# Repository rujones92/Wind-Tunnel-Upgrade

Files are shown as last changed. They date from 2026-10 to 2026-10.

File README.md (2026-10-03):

# Wind Tunnel Upgrade: motorized 6-component sting balance

## ▶ View the website: [rujones92.github.io/Wind-Tunnel-Upgrade](https://rujones92.github.io/Wind-Tunnel-Upgrade/)

This repository hosts the design package for a motorized sting force balance for a university low-speed wind
tunnel (test section 26.25 × 11.25 × 30 in, 70-100 mph). The tunnel tests 3D-printed aircraft models. A one-piece
aluminium strain-gauge balance measures all six force and moment components. Stepper motors roll (±90°), pitch
(-6° to +20°) and yaw (±15°) the model, controlled from a Raspberry Pi station.

Open the link above to browse the package. GitHub's file view shows `index.html` as source code, so use the
website link instead. The website includes:

- **Overview, Requirements, Balance, Models & pod, Motion, Electronics & control, Calibration:** the design and how
  it works, with CAD renders and wiring diagrams
- **Drawings:** 35 GD&T sheets (assemblies with parts lists and every machined part), as PDF
- **Machining cost:** a real JLCCNC quote, the expected final order and an ordering checklist
- **Implementation plan, Design history, References:** phases, budget, risks, literature, and downloads of all STEP
  files and scripts

The drawings are REV A and AI-assisted. They have not yet been checked or approved for manufacture. Yaw-carriage
sheets (5xx) are preliminary until the tunnel's downstream bay is measured.

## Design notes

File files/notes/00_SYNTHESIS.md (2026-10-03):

# Reference review — synthesis (2026-10-02)

Combined from 7 reader agents (276 pages, read as page images + text layer). Per-document notes are in this folder.
Reviewed against `balance_sizing.py` (7075-T651, 3-component, two-moment necks + 2-plate Z axial flexure).

## What the references confirm
- Monolithic balance; fwd moment section → axial section → aft moment section (LaRC Figs 4, 5, 8).
- 7075 is on LaRC's material list; 350 Ω gauges, 5 V excitation, 4-active-arm bridges, CEA-13 on aluminum.
- Necks 0.50 × 0.25 in → 1.03 mV/V, inside LaRC's 1–1.5 mV/V target; combined-load SF 10.7.
- Independent check: Bharath 8 mm square neck has the same section modulus (0.0052 in³) → same ~520 µε.
- Two-moment method with BMC midway between gauges is exactly the Gulfstream balance in the NASA 2010 calibration paper.

## Design changes indicated
| # | Issue | Source | Change |
|---|---|---|---|
| 1 | Axial output 0.78 mV/V < 1.0 target | LaRC p.8–9 | Raise strain. Note: plate t=0.020" gives 1.21 mV/V but is fragile and hard to gauge |
| 2 | Axial gauges sit on load-carrying plates (~107 µε of N/m strain vs 388 µε signal) | LaRC Fig 8 | Preferred: two ungauged outer flex plates + one centreline gauged measuring beam |
| 3 | Gauge centre 0.06" from root too close for gauge backing/tabs and fillets | Gage proc. p.7; LaRC p.9 | Root fillets r≈0.03–0.06"; gauge centres ≥0.08–0.10" from fillet; recompute |
| 4 | Clamping 60 psi on a 0.025" plate in a 0.75" window | Gage proc. p.7, p.30 | Clamp both inner gauges in one stack with backing blocks outside both plates; 0.75" window is minimum |
| 5 | Hot-cure adhesive (M-610/M-450 at 340–350°F, hours) over-ages 7075-T651 (aged ~250°F) | Gage proc. p.7, p.70 | Use reduced cure (M-610 250°F/3 h + 275°F post, p.32) or AE-10 room-temp; or switch to 17-4PH H1025 |
| 6 | Resolution assumption 0.05% FS too optimistic | LaRC Figs 14–15 | Budget 0.2–0.5% FS (LaRC itself: 0.06–0.17%, 2σ) |
| 7 | Cruise drag is only 5–15% of 2 lbf axial FS | LaRC p.3–4 | Consider ~1 lbf axial FS with hard stops, or a second low-range balance for polars |
| 8 | No temperature sensing | LaRC Fig 12; Gage proc. p.8–9 | RTD/thermistor on balance; matched-lot gauges; software temperature correction |
| 9 | Sting/pod ratio 1/2 = at limit | TN D-4021 p.5 + Love ref. | 7/8" sting or 2.25" pod (ratio ≈0.44); ≥10–12" straight sting before flare (≥5 base dia) |
| 10 | Base/cavity pressure not handled | TN D-4021 p.8 | 2–4 base taps + 1 cavity tap; subtract (p_base − p∞)·A_base from axial |
| 11 | Joints undefined | LaRC p.6–7 | Model end: bore fit + interference dowel; sting end: flange (preferred) or 1 in/ft taper + key + double nut |
| 12 | Wiring across flexures | Gage proc. p.7–8; part 2 p.57–64 | Terminals on shoulders/rails, not necks; groove for wires crossing axial flexure; strain-relief loops |

## Calibration plan (NASA 2010, Ulbrich & Bader)
- Responses: neck-output difference (∝ N) and sum (∝ m), plus axial. Regress against BMC loads.
- Term selection: start intercept + main term, add terms only if p < 0.001, VIF < 5, PRESS improves. Full quadratic overfits (VIF ~23,000).
- Schedule: ~90 fit points + 10–15 withheld check points; N at BMC and ±1, ±2 in (both sides of BMC to decorrelate N and m); pure couples; A alone and combined with N, m; load up and down; flip balance for negative loads.
- Re-level with an inclinometer after each load (0.18° deflection tilts N into A by 1.5–3% of A FS).
- Expected sensitivities: ~36.9 µV/V per in-lbf per neck; difference ≈ 88.6 µV/V per lbf; sum ≈ 73.9 µV/V per in-lbf.
- Acceptance: residual SD ≤ 0.1–0.25% FS, max residual ≤ 3σ, PRESS ≈ fit residual, check-point errors in load units.

## Gauge installation & checks (NASA TM-110327)
Degrease → abrade (hobby: acid conditioner/neutralizer) → bond (±0.005" placement) → cure → wire with equal-length leads → checks:
leakage > 10,000 MΩ at ≤15 V (megohmmeter), zero within ±0.4 mV/V (Manganin trim or amplifier offset), tap test, hand-load test,
warm-box zero drift test, thin moisture coat (≤0.005", identical on both plates; RTV over terminals only).
Avoid M-Bond 200 (cyanoacrylate) for a long-life balance.

## Alternative (2014 external 6-comp paper)
External platform balances reach ~0.3% FS but strut drag lands in the drag reading; roughly 3–5× the work for 6-comp.
Keep internal sting balance as primary; 3-component floor platform as fallback.

## Papers worth obtaining next (cited by the references)
- Love, NACA RM L53K12 (sting diameter and length effects) — free on NTRS
- Webb/Ladson 2001 monolithic balance thesis; Pieterse 2008; Lee et al. 2005
- "A Three-Component Strain-Gauged Sting Balance for Small Low-Speed Wind Tunnels", Aeronautical Journal (paywalled)

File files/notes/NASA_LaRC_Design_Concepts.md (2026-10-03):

# NASA LaRC Strain Gage Balance Design Concepts (Rhew, 1999) - reading notes

Source: `references/NASA_LaRC_Strain_Gage_Balance_Design_Concepts_1999.pdf` (18 PDF pages; journal pages 525-541, PDF p.18 is blank).
Page references below are given as **PDF page (journal page)**, e.g. p.10 (534).

## 1. Summary

An overview of how NASA Langley designs, builds, gauges and calibrates internal sting-mounted six-component balances. It is a process and philosophy paper, not a design handbook. It gives only a few hard numbers (output target, materials and hardness, EDM tolerances, bridge zero-balance limit, gauge and adhesive part numbers, calibration matrix size and achieved accuracy). It has **no sizing formulas** apart from the strain-output relation. Its core messages:

1. Make the balance from **one piece of material** (no joints). Joints cause hysteresis and zero shift.
2. **Match the balance's full-scale loads to the test's expected loads** to get the best resolution.
3. Size each measuring section for **1-1.5 mV/V at full scale**, while keeping strain safe under **all six loads applied together**.
4. Make each bridge sensitive to its own component and insensitive to the others. Do this through the section geometry, gauge placement and bridge wiring.
5. Do the work carefully: EDM finishing passes, tolerances of 0.0002-0.0005 in, an experienced gauger, temperature compensation, and a full second-order calibration.

## 2. Design rules and numeric criteria

### Inputs needed before design (p.4 / 528)
Expected loads in all 6 DOF; where the balance sits in the model; maximum diameter and length; environment (temperature, pressure, moisture, dynamics, airflow, corrosion); model-end (metric) and sting-end (non-metric) interfaces; required accuracy and resolution; electrical interfaces; DAQ specs; data-reduction software; set-up and checkout equipment. Start from a similar past design. Iterate with strength-of-materials code; FEA is "beginning to be evaluated" for stress concentrations, thermal behaviour and optimisation.

### Load matching (p.3-4 / 527-528)
- Make full-scale (FS) loads match the expected test loads as closely as possible. This gives the best resolution.
- If one test spans very different regimes, it is better to build **two balances** (e.g. one for performance and one for stability and control).

### Materials and heat treatment (p.6 / 530)
| # | Material | Condition | Use |
|---|---|---|---|
| 1 | 17-4 PH or 15-5 PH stainless | H925, Rc 40-42 | most common |
| 2 | C-200 18% Ni maraging | H900, Rc 41-45 | cryogenic |
| 3 | C-300 18% Ni maraging | H900, Rc 52-55 | high capacity |
| 4 | 2024-T4 aluminium | | |
| 5 | **7075-T6 aluminium** | | |
| 6 | Be-Cu | | extreme temperatures |
- The material must have "transducer quality". Choose it early using simple diameter-to-load calculations. A more ductile, lower-strength material is sometimes preferred.
- Also consider corrosion and moisture, and how well gauges bond to and behave on the material.
- Heat treat to the vendor's spec **after rough machining and before EDM**. Certify with a Rockwell C hardness test (p.10 / 534).

### Sting and model interfaces (p.6-8 / 530-532; Figs 6, 7)
- **Sting end:** a tapered cylinder at **1 in/ft taper**, with a **keyway for roll reaction**, held by a **double nut** (standard) or set screws (for small balances or cryogenic use). Taper maximum diameters range from 0.3125 to 5.0 in.
  - Drawbacks: the taper is hard to machine and wears. The keyway is a sliding fit, so it has roll slop, and the key bears on a small area.
  - LaRC prefers a **flange fit** where the diameter allows. Most semi-span balances use one.
- **Model end:** a cylindrical fit with an **interference-fit dowel pin** that locates the model. This joint defines the load axes, so any misalignment shows up directly as error.
  - The "front-end expander" (Fig 7) expands a sleeve into the model bore. Sizes range from 0.625 to 3.1 in. It is not used for cryogenic work or for high load-to-diameter performance balances.
  - Roundness, cylindricity and the true position of the dowel hole are critical.

### Measuring sections (p.8-10 / 532-534; Figs 8, 9)
- There are usually **three sections**: one **axial** section, and two **"cage" sections** (forward and aft) that between them resolve N, m, Y, n and roll. This is the two-moment (two-station) concept.
- **Output target: 1 to 1.5 mV/V at FS.**
- Strain relation for a 4-active-arm bridge: `strain = Vout / (Vin x GF)`, i.e. Vout/Vin = GF x strain (p.9 / 533).
- Iterate the design to reach that output while keeping strain "safe" with all six components applied at once.
- **Axial section (Fig 8):**
  - The gauged **measuring beam** is a "slotted-T" beam (one per side), placed **as close to the balance centreline as possible** to minimise moment effects.
  - The slot makes it act as a **single bending beam** and reduces its strain under normal force.
  - **Separate flex beams** (14 per side on the NTF balance) carry the other loads, which reduces the load passed into the measuring beam.
  - In short, the gauged element is **separated from the load-carrying flexures**.
- **Cage sections (Fig 9):**
  - Beams usually have a rectangular cross-section.
  - **Notched or "stress-riser" beams** are used to raise sensitivity when needed.
  - **Stiffening end shoulders** transition the beams into the model and sting ends to **minimise nonlinearities**.

### Fabrication (p.10-11 / 534-535; Fig 10)
1. Material certification plus ultrasonic inspection for voids (NASA TM 84625), for fatigue and fracture reasons.
2. Conventional rough machining (turn, mill, grind), followed by an in-process QA check.
3. Heat treat, with certification and an Rc hardness test.
4. Wire and plunge EDM.
   - Use wire EDM wherever possible for flats and through-holes (cages, axial outline).
   - **Three EDM passes:** one rough pass in fast mode to within about **0.050 in** of final size, then **two slow finishing passes**. The finishing passes control tolerance and limit the EDM recast damage that reduces fatigue life.
   - Measuring-beam tolerance is **0.0005 to 0.0002 in**.
5. QA to about 0.0002 in (CMM, height gauges, bore, ring, plug and taper gauges), with a report of actual versus design dimensions.

### Strain gauging (p.11-13 / 535-537; Fig 11)
- Use a gauger with more than 5 years of transducer-quality experience. Check all surfaces under a microscope for sharp edges and defects first. Procedures: NASA TM 110327 (Moore, 1997).
- Materials:
  - **Gauges:** Micro-Measurements C-891113-A or -B, **350 ohm**
  - **Adhesive:** **M-Bond 610** (heat-cured epoxy)
  - **Moisture protection:** GageCoat 8 or **M-Coat B**
  - **Solder:** MM 361A
  - **Wire:** stranded **silver-clad copper, Teflon insulated, AWG 30-44**
  - **Temperature sensors:** type J or T thermocouples, Hy-Cal EL-700T platinum RTD
- After installation, a QA check of gauge location and alignment.
- **Bridge (Fig 11):** 4 active arms. Gauges 1 and 3 are in tension and 2 and 4 in compression, placed in opposite arms so their outputs add.
  - A **thermal-compensation wire** (nickel, with silver-clad copper) sits in series in one arm.
  - A **bridge-balance wire** (Manganin) sits in another arm.
- **Zero balance within 0.4 mV/V** using Manganin wire.
- **Temperature compensation:** add nickel wire to cancel output drift with steady temperature at constant load.
  - Fig 12 shows a typical acceptance run from 80 to 180 to 80 F.
- **Wiring:**
  - Use twisted shielded pairs (signal and power) where possible, with an outer sleeve of nylon or fibreglass.
  - After wiring, **temperature-cycle the balance over its operating range +50 F** to relieve the wiring.

### Calibration (p.13-16 / 537-540; Figs 13-15)
- Calibrate in conditions as close to the tunnel's as possible. Most LaRC balances are calibrated at room temperature to full scale.
- **Math model:** a 6x27 **second-order iterative** model. Each output is a sum of 6 linear terms, 6 squares and 15 cross-products. It is inverted to give: corrected load = output x sensitivity - sum of interaction terms.
- **Load schedule:**
  - **729 loading points**, followed by **3 proof loadings** (two three-component and one six-component combined) to verify the matrix.
  - Accuracy is reported as **2-sigma of back-calculated residuals**.
- **Hardware and technique:**
  - Manual dead-weight stands.
  - Loads applied through a **double knife edge**.
  - Moments applied by the **long-arm technique**.
  - The balance is **re-levelled after every load**.
  - Horizontal loads use cables over a **bell crank** instead of a pulley, to cut friction.
  - Precision-machined fixtures.
- Temperature calibrations use strip heaters or LN2. Automatic calibration systems were under review at the time.

## 3. Figures - what each one teaches
| Fig | PDF p. (jnl) | Content | Lesson |
|---|---|---|---|
| 1 | 2 (526) | Transport model with an internal balance; arrows for N, A, Y, roll, pitch, yaw | LaRC sign and naming convention for the 6 components |
| 2 | 2 (526) | Photo of LaRC's first internal balance, 1940s, multi-piece | Bolted, screwed or welded construction leads to slop |
| 3 | 3 (527) | Calibration curve: output (uV/5V, 0-60) vs load (% FS); loading and unloading branches differ (hysteresis, a few uV), and the curve does not return to 0 (zero shift, ~5 uV) | Joints and friction show up as hysteresis and zero shift. One-piece construction fixes this (EDM made it possible, c.1958). |
| 4 | 5 (529) | UT-57 balance photo: model end with expander and dowel hole on top; three measuring sections; sting-end taper, threads, keyway | General layout: model end -> cage -> axial -> cage -> taper |
| 5 | 5 (529) | NTF balance photo: model end (diameter fit, dowel), cage-axial-cage, taper with keyway | Same layout, cryogenic version |
| 6 | 7 (531) | Drawing of a tapered sting end: 1 in/ft taper, keyway, thread for double nut, set screw at 30 deg | Standard sting joint. Note the roll slop from the sliding key. |
| 7 | 8 (532) | Expander front-end: forward taper, expander sleeve, expander guide key, gear and pinion drive, model dowel | Adjustable cylindrical model fit; complex |
| eq. | 9 (533) | strain = Vout / (Vin x GF) | For 4 active arms, 1 mV/V = 500 ue at GF 2 |
| 8 | 9 (533) | NTF measuring sections: axial slotted-T beam (one per side) between flex beams (14 per side); two cage sections, each with "two 6-sided beams" gauged for 5 components | **Gauged axial beam is separate from and on the centreline of the flexures that carry N and m** |
| 9 | 10 (534) | Two cage cross-sections (Section AA). (a) **0.65 in dia, scale 2:1**, for N 50 lb, A 10 lb, m 100 in-lb, roll 10, yaw 15 in-lb, Y 15 lb. Small rectangular beams (~0.08 x 0.04 in, 0.06/0.09 in features, ~0.03 in slots) around a thin central web. (b) **1.50 in dia, 1:1**, for N 800 lb, A 60 lb, m 2000 in-lb, roll 800, yaw 1000 in-lb, Y 400 lb. Centre beams 0.25 in wide top and bottom, flanked by 0.125 in beams, side beams ~0.20 in, overall depth 0.68/0.48 in. | Each beam arrangement is tuned to the component ratios. Small balances still use beams only a few hundredths of an inch thick. (Small digits are hard to read; values ~+/-0.005.) |
| 10 | 11 (535) | Balance in a plunge EDM machine | EDM is the main finishing process |
| 11 | 12 (536) | Bridge diagram: G1 (T) and G3 (T), G2 (C) and G4 (C) in opposite arms; thermal-compensation wire in the G4 arm; bridge-balance wire in the G2/G3 corner; +/-V and +/-signal | 4-arm bridge with series nickel thermal compensation and Manganin zero balance |
| 12 | 13 (537) | Temperature run, output (uV per 5 V) vs T, 70-180-80 F. Output drifts from ~0 to ~-15 uV/5V (~3 uV/V) over ~100 F, with a small loop between up and down | Typical *accepted* thermal zero drift is ~0.03 uV/V/F, i.e. ~0.3% FS per 100 F on a 1 mV/V balance |
| 13 | 15 (539) | Dead-weight stand photo: bell crank, pitch/yaw moment arms, double knife edge, balance in fixture | Calibration rig elements worth copying in a DIY version |
| 14 | 15 (539) | Calibration cover sheet for balance UT62A at 5 V excitation. N 500/-600 lb gives 1.214 mV/V, accuracy 0.06% FS. A 60 lb gives 1.003 mV/V, 0.17%. Pitch 1800 in-lb gives 1.548 mV/V, 0.06%. Roll 400 in-lb gives 1.032 mV/V, 0.14%. Yaw 600 in-lb gives 1.258 mV/V, 0.16%. Y 200 lb gives 0.996 mV/V, 0.14%. | Real LaRC outputs are **1.0-1.55 mV/V**. Achieved accuracy is **0.06-0.17% FS (2 sigma)**. Axial is the hardest. 5 V excitation is standard. |
| 15 | 16 (540) | Interaction sheet for the N bridge. Linear: pitch +1.28% FS, roll -1.14%, side -0.09%. Second-order terms are all <=0.12%. | Even LaRC balances have **~1% first-order interactions**. The calibration matrix must remove them. |

## 4. Directly applicable to our design
- **Monolithic 7075 aluminium** is on LaRC's approved list (#5, as 7075-T6; our T651 is the same temper, stress-relieved, which is better for machining stability).
- The **1-1.5 mV/V target** and the 4-arm `GF x strain` relation are exactly what `balance_sizing.py` uses. Our design is at the bottom of the band.
- The **two-station (fwd and aft cage) plus separate axial section** layout matches our fwd neck - axial - aft neck layout (Figs 4, 5, 8).
- **350 ohm gauges** and **5 V excitation** match LaRC practice (Fig 14).
- Calibration approach, scaled down to 3 components: a **3x9 second-order model** (3 linear, 3 squares, 3 cross-products), dead weights through knife edges, long moment arms, re-levelling after each load, and combined-load proof checks.

---

## 5. Critique of the current first-pass design (balance_sizing.py)

Script results: necks 0.50 W x 0.25 H, 517 ue, 1.03 mV/V, SF 13.6 (10.7 von Mises with Y, l, n). Axial plates 0.025 x 0.75 x 0.75 in, 388 ue, **0.78 mV/V**. Plate axial load from N and m is 20.8 lbf (1,111 psi, ~107 ue).

### Confirmed by the paper
1. One-piece construction (p.3 / 527): yes.
2. Two moment stations plus a separate axial section (Figs 4, 5, 8): yes.
3. Neck output of 1.03 mV/V is inside the 1-1.5 mV/V target (p.8 / 532).
4. The stress check with all loads applied together, including the unmeasured Y, roll and yaw, follows LaRC's rule of a safe strain "when all six components are applied simultaneously" (p.8 / 532).
5. 7075 aluminium, 350 ohm gauges and 5 V excitation are all LaRC practice (p.6, p.12, Fig 14).

### Contradicted or weak
1. **Axial output 0.78 mV/V is below LaRC's 1.0 mV/V minimum** (p.8 / 532). Axial is also the component with the worst achieved accuracy (0.17% FS, Fig 14).
2. **The gauged axial element also carries the main load.** Our gauges sit on the same two plates that carry N and m. Each plate sees ~107 ue of direct strain against a 388 ue signal, and only bridge symmetry cancels it. LaRC deliberately separates a **centreline gauged measuring beam** from the **load-carrying flex beams**, and slots it so it acts as a single bending beam (p.9 / 533, Fig 8). Our N->A interaction will depend heavily on how well the plates are matched and how accurately the gauges are placed.
3. **Load matching** (p.3-4 / 527-528).
   - Expected N is ~7.1 lbf against 15 lbf FS (47%).
   - Cruise drag is ~0.1-0.3 lbf against 2 lbf FS (5-15% of FS).
   - LaRC would suggest a lower axial FS (protected by overload stops), or a separate "performance" balance with a lower FS.
4. **Accuracy assumption is too optimistic.** The script uses 0.05% FS. LaRC's best balances achieve 0.06-0.17% FS (2 sigma) (Fig 14). A DIY balance should budget **0.2-0.5% FS**.
5. **No transition shoulders or fillets** are specified at the neck and plate roots. LaRC uses stiffening end shoulders to reduce nonlinearity (p.9 / 533). Our plate gauges sit only 0.06 in from the root, right in the root stress gradient.
6. **Interfaces are undefined.** LaRC treats the model joint as the most critical in the test (p.7 / 531).
7. **No temperature compensation or temperature sensor is planned.** A closed-return tunnel heats up during a run. Fig 12 shows that even a compensated balance drifts ~3 uV/V per 100 F (~0.3% FS).

### Recommended changes
1. **Raise axial output to at least 1.0 mV/V.**
   - Reduce plate thickness to **0.022 in** (501 ue, 1.00 mV/V, buckling SF 5.8, k = 394 lbf/in).
   - Or reduce it to **0.020 in** (606 ue, 1.21 mV/V, buckling SF 4.4, k = 296 lbf/in). This is preferred: it sits mid-band.
   - Narrowing the plate to about 0.60 in has a similar effect.
   - Re-set the stop gap so engagement is about 1.2-1.5x FS. At 0.020 in plates, a 0.010 in gap engages at ~3.0 lbf. A 0.008 in gap gives ~2.4 lbf.
2. **Consider the LaRC axial topology.**
   - Use two outer flex plates (carry N and m; ungauged; can be thicker) plus **one central, slotted gauged measuring beam on the balance centreline**.
   - Or, as a minimum, specify plate thickness matching within **0.0005 in** between plates and place the gauges symmetrically. Then check the N->A interaction in FEA.
3. **Add root fillets and shoulders** (about r = 0.03-0.06 in) at the plate and neck ends. Move the gauge centres to about 0.10 in or more from the fillet tangent and verify uniform strain under the grid with FEA.
4. **Machine the necks and plates by wire EDM** (a job shop can do this). Specify one rough pass plus two skim (finishing) passes and hold ±0.0005 in. Fatigue and recast matter less at our low stresses (5-14 ksi) but still matter.
5. **Gauging:**
   - Use **M-Bond 610** (heat-cured), not cyanoacrylate.
   - Protect with **M-Coat B**.
   - Wire with stranded silver-plated Teflon AWG 30-36 and run leads in twisted shielded pairs.
   - Zero the bridges to **within 0.4 mV/V** with Manganin trim.
   - Plan for **nickel-wire thermal-zero compensation**.
   - Temperature-cycle the finished balance over the expected range +50 F.
   - **Fit an RTD or thermocouple on the balance.**
6. **Interfaces:**
   - Model end: a cylindrical bore fit plus an interference dowel inside the 2 in pod.
   - Sting end: a **1 in/ft taper with key and double nut**, or (since we are not diameter-limited) a **flange fit**, which LaRC prefers for roll stiffness.
7. **Calibration:**
   - 3x9 second-order matrix.
   - Knife-edge load points and long moment arms.
   - **Re-level after each load.** Model pitch deflection at FS is 0.18 deg, which is not negligible.
   - Combined N+A+m proof loads.
   - Report 2-sigma back-calculated error.
   - Expect ~1% FS first-order interactions (Fig 15).
8. **Keep the design loads honest.** Consider an axial FS of about 1 lbf with hard stops, or plan a second, lower-range axial element if drag polars at cruise are the main goal (p.4 / 528).

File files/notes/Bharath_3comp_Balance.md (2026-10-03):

# Bharath Institute - "Design and Fabrication of Three Components Internal Strain Gauge Balance"

Source: `references/Bharath_3comp_Internal_Balance.pdf` (68 PDF pages; B.Tech project report, Guru Sankar, Nikhil, Naga Saikiranmai, Navya; guides C. Suresh Kumar / M. Ramakrishna; Bharath Inst., Chennai, May 2021).
Page numbers below are **PDF page numbers** (report page number in brackets where useful). PDF has a usable OCR text layer; figures were checked from the page images.

## 1. Summary

A 4-student undergraduate report. They CAD-modelled (CATIA) a 300 mm long round cantilever "sting balance" with two reduced 8 mm square sections, ran a long series of linear ANSYS static cases (deflection and some von Mises stress) for steel vs aluminium under "longitudinal" (lift), "axial" (drag) and "torque" (they call it pitching moment) loads, compared tip deflection against hand formulas, and machined one aluminium part with a gauge stuck on it. **There is no bridge design, no gauge layout, no output/sensitivity calculation, no calibration, no interaction matrix and no wind-tunnel test.** The conclusion's "sensitivity" and load-range claims are not supported by any data. Credibility: low. It is useful mainly as a list of mistakes to avoid.

## 2. Page map

| PDF p. | Content |
|---|---|
| 1-16 | Title, certificates, acknowledgements, abstract (p6), contents/lists |
| 17-19 | Ch.1 strain-gauge basics (generic, partly copied vendor marketing text, e.g. Encardio-Rite, p18) |
| 20-22 | Ch.2 literature review (Pieterse 2008, Hou & Twu, Lee et al. water-tunnel balance, Ladson/Webb monolithic balance, Tomin 2020) - one-paragraph summaries |
| 23-25 | Ch.3 concept: 15 mm dia x 300 mm cantilever with two 8 mm square sections |
| 26-27 | Ch.4 CAD (Fig 4.1-4.3) and dimensioned drawing |
| 28-34 | 5.1 lift-only loading: FEA pictures, Table 1 (FEA) & Table 2 (hand calc) deflection 1-300 N, Fig 5.1.7 |
| 35 | 5.2 mesh (tet, 233,328 nodes / 156,000 elements) and "mesh independence" (tip deflection only) |
| 36-38 | 5.3 "torsional" (pitching-moment) analysis, Table 3 twist angles |
| 38-48 | 5.4 combined drag + lift: FEA pics, Table 4 (FEA), beam-column formula and Table 5 (hand) |
| 49-63 | 5.5/5.6 moment + lift, moment + axial: FEA pics, Table 6 (von Mises stress), Tables 7-9, charts |
| 64-65 | Ch.6 results/discussion: bridge types in words, model mounting, DAQ, Fig 6.1-6.2 photos of fabricated part |
| 66 | Ch.7 conclusion (load range / "sensitivity" claims) |
| 67 | References (7) |
| 68 | blank |

## 3. Their balance geometry (p24-27, p65)

- One-piece round bar, overall 300 mm. Drawing Fig 4.3 (p27) dimension string: **60 | 40 | 100 | 40 | 60 mm**.
  - Two 60 mm end lugs (round, ~15 mm dia) each with two transverse cross-holes (dims read Ø5.04 / Ø5.09 mm) for screws/pins: one end attaches to the model, the other to the sting.
  - Two 40 mm long **8 x 8 mm square necks** (gauge sections), milled from the round stock.
  - A 100 mm round centre section between the necks.
  - Neck centre-to-centre spacing therefore ~140 mm (5.5 in). Neck-to-shoulder transitions drawn with sharp corners (no fillets).
- Body diameter: text says 15 mm (p24); front view label is hard to read.
- Text: "incentive of circular cross-section is to extract the pitching moment" (p24) - no actual explanation of how N, A, m are separated.
- Material: aluminium (E = 71.7 GPa, G = 26.9 GPa - the MatWeb 7075-T6 modulus, but alloy/temper never stated) and steel (E = 210 GPa, G = 77.2 GPa) both analysed; the fabricated part (p65) is aluminium.
- **No dedicated axial (drag) element.** Abstract (p6) admits axial strain is too small to measure with gauges directly, yet the report still claims 3 components.

## 4. Design loads

- Never derived from any tunnel/model aerodynamics. Arbitrary sweeps: lift 0.1-300 N, drag 5-300 N, "torque" 2-10 N.m (p28-63).
- "Beam is designed to withhold maximum sensitivity of 100 grams" (p24) vs "minimum load of 100 grams" (p25) - contradictory.
- Conclusion (p66): aluminium "load capacity 1-100 N, sensitivity 1 N with full bridge"; steel "5-300 N, sensitivity 5 N". No calculation or test supports these numbers.

## 5. Calculations (and errors)

**Bending deflection (p31-34):** I_circle = pi d^4/64 = 0.2485e-8 m^4 (correct for 15 mm). Then:
- I_square computed as bd^3/12 + db^3/12 = 0.0682e-8 m^4 - this is the polar value; bending I of 8 mm square is 0.0341e-8.
- Then "I = I_c - 2 I_sq - 2 I_screw" = 0.107e-8 m^4 - physically meaningless (subtracting the inertia of the neck from that of the round bar). A stepped cantilever must be handled by integrating M/EI along the length.
- delta = WL^3/3EI = 11.73 mm at 100 N (Al) - arithmetic consistent with their I, and FEA gives 14 mm (Table 1, p30-31), so the agreement is ~15-20% and partly luck.
- p60 uses yet another I (1.04e-9) for the same beam.

**"Torsion" = pitching moment (p36-38, p61):** they apply the pitching moment as a torque about the balance's long axis (FEA images p36-37 show twist about the bar axis) and compute twist = TL/GJ. Pitching moment is a bending moment about the lateral axis, not torsion - torsion about the sting axis is rolling moment. Additionally Table 3 values labelled "rad" are actually **degrees** for aluminium (my check: 10 N.m, 0.3 m, G 26.9 GPa, J of 15 mm rod -> 0.0224 rad = 1.286 deg; table says "1.286 rad"); steel column is ~2x the correct 0.448 deg.

**Combined lift + axial (p46-48):** beam-column formula delta = (W/P)(tan(uL)/u - L), u = sqrt(P/EI) (compressive axial). Reasonable formula, but Table 5 is garbled and the values repeat in blocks (0.0006, 0.006, 0.012 ...) independent of axial load - looks copy-pasted. Pcr of their beam ~2.1 kN (Al), so 300 N axial gives only modest amplification anyway.

**Stress (p53-58, Table 6 p58):** von Mises max = 35.7e7 Pa (2 N.m + 5 N) up to **103-104e7 Pa = ~1030 MPa** at 300 N lateral, identical for steel and aluminium (expected - statically determinate). They never compare this to yield: 1 GPa is ~2x 7075-T6 yield and above most steels. Table 6 is also internally inconsistent (6 N.m + 5 N gives 100 MPa, less than 2 N.m + 5 N at 357 MPa). Torque column units given as "N/m".

**Strain / bridge output:** never calculated. My check with their geometry (moment arm to the root-side neck ~0.24 m, Z_sq = 8.53e-8 m^3): 1 N -> 2.8 MPa, 39 ue; 15 N -> 590 ue; 100 N -> 281 MPa, 3900 ue (Al) - i.e. their claimed 100 N "capacity" is ~8x the usual 500 ue design strain and at/above yield for 6061. Axial: 8.9 N (2 lbf) on 64 mm^2 -> **~2 ue** - unmeasurable, confirming the abstract.

**Text errors on bridges (p19, p64-65):** "strain gauges don't get influenced by temperature" (wrong); "full bridge sensitivity is twice the quarter bridge" (a 4-active-arm full bridge is ~4x a quarter bridge; 2x is a half bridge); bridge output formula garbled.

## 6. FEA

ANSYS R18 static structural, tetrahedral mesh 233,328 nodes / 156,000 elements (p35). Mesh "independence" checked only on tip deflection (flat at ~0.005 m, p35) - not on stress at the neck, which is what matters. One end fixed, point load / moment at the other end. Results are deflection contours and a few von Mises plots; no strain extraction at gauge locations, no cross-coupling study. Load sweeps are huge in number (~90 figures) but low in information.

## 7. Gauge placement, wiring, fabrication, calibration

- Gauges: "attached on the square sections" (p24). Photo Fig 6.2 (p65) shows one foil gauge on a neck flat with two red leads - looks like a quarter-bridge trial ("we had tried with quarter bridge configuration", p65). No gauge type, resistance, GF, adhesive, layout, bridge assignment or temperature compensation stated.
- Fabrication (p65 Fig 6.1): aluminium bar, turned round with milled square necks and cross-drilled end lugs. Looks lathe + mill; no surface finish, fillet or heat-treat info.
- Mounting: model "mounted rigidly with the screws ... model gets in contact with the balance only at the point of contact with the strain gauges" (p65) - confused; if the model touches the gauged sections it creates a load short-circuit.
- DAQ: generic "DAQ connected via serial connector ... report software" (p65).
- **Calibration: none.** "Further scope of work is to practically analyze the beam" (p65). No sensitivities, interactions, linearity or errors.

## 8. Assessment

Student work with fundamental errors: pitching moment modelled as torsion; wrong section property method; degrees reported as radians; FEA stress far beyond yield not noticed; no axial element; no strain/bridge/output sizing; no calibration or test data; conclusion numbers unsupported. Literature review is superficial but the reference list points to better sources (Pieterse 2008 Stellenbosch thesis; Lee et al. 2005 water-tunnel balance; Webb/Ladson 2001 monolithic balance thesis - those are worth reading instead). **Do not use any numbers from this report as design data.**

## 9. Comparison with our design (balance_sizing.py)

**Numbers that check/contradict:**
- Their 8 mm (0.315 in) square neck has section modulus 0.00521 in^3 - essentially identical to our 0.50 W x 0.25 H neck (0.00521 in^3). At our worst neck moment (28 in-lbf = 3.16 N.m) both give ~5,400 psi / ~520 ue, which is what our script targets. Independent geometry, same answer - mild sanity check of our sizing, nothing more.
- Their beam with no axial flexure gives ~2 ue for our 2 lbf drag -> strongly supports our decision to use a dedicated parallelogram axial flexure (~500 ue).
- Their neck spacing is 5.5 in on a 11.8 in long balance; ours is 2.4 in. Their balance would not fit our ~2 in pod / 30 in test section layout; our shorter spacing is appropriate but costs N resolution (script already accounts via sqrt(2)*M_res/s).
- Their 1 N "sensitivity" claim would correspond to ~39 ue (~0.08 mV/V full bridge), plausible as a resolution figure but they never measured it.

**Mistakes to avoid (all relevant to us):**
1. Pitching moment is bending about the lateral (y) axis, not torsion; roll is the torsion load - our script already treats roll as torsion on the necks (correct). Make sure FEA load cases apply m as a bending moment.
2. Do mesh convergence on **stress/strain at the gauge location**, not tip deflection.
3. Always compare FEA von Mises to yield with an overload case (they reached ~1 GPa unnoticed). Our script does SF checks - keep that for the FEA too, including cross-hole and fillet stress concentrations.
4. Fillet neck/flexure transitions; keep attachment cross-holes well away from gauged sections (their lugs with Ø5 mm cross-holes sit right next to the necks).
5. Use 4-active-arm bridges with temperature-matched gauges (STC for 7075); a single gauge in quarter bridge is not a balance.
6. The model must touch the balance only at the model-end attachment - any contact elsewhere (they describe contact "at the strain gauges") short-circuits load.
7. Plan calibration from the start (load jig, weights, interaction matrix) - the report stops at fabrication.

**Useful ideas (minor):** round bar with milled flats for necks is an easy, cheap manufacturing route; cross-drilled pin/screw lugs at both ends for model and sting attachment (we would prefer a taper or keyed/dowelled flange for repeatability).

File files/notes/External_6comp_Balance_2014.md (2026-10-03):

# External Six-Component Strain Gauge Balance for Low Speed Wind Tunnels (2014)

Samardzic, Anastasijevic, Marinkovski, Curcic (Military Technical Institute VTI, Belgrade), Isakovic.
*Scientific Technical Review*, 2014, Vol. 64, No. 3, pp. 40-46. 7 PDF pages.
Page refs below: "p.N" = PDF page N (journal page = N + 39).

## 1. Summary

The paper describes a **platform-type external 6-component balance** for small low-speed tunnels
(test section 0.4-0.6 m x 0.4-0.6 m, up to 50 m/s; p.1-2). The model sits on two struts (main + tail)
that are fixed to a triangular platform. The platform is held by six rods with elastic pivot flexures,
and each rod loads one single-force strain-gauge load cell: 3 vertical and 3 horizontal. The cells sit
under the test-section floor. A pitch/yaw positioning system is built in. All six cells use the same
gauged closed-frame flexure ("binocular" style), made from PH 13-8 Mo stainless steel. Each cell was
calibrated on its own to 0.05% FS. The assembled balance was then calibrated with dead weights and a
linear 6x6 matrix fitted by least squares. Per-cell error is about 0.25% FS (3 sigma). Errors on the
composite components reach 0.89% FS for pitching moment because no combined loads were applied in the
calibration (p.4).

The paper is short. It gives **no flexure dimensions** (the symbols Lt, b, h are defined but no values),
no electronics/DAQ details beyond the excitation voltage, and no stiffness or deflection data.

## 2. Balance architecture (p.2, Fig.1, Fig.3; p.3, Fig.4)

- Platform-type external balance. Parts (Fig.1 legend): 1 model, 2 main support strut, 3 tail support
  strut, 4 triangular platform, 5 pivot flexures, 6 rods, 7 load cells, 8 rotating frame,
  9 fixed frame, 10 pitch mechanism, 11 yaw mechanism, 12 step motor.
- The model hangs on 2 struts (main strut near the CG, tail strut aft for pitch) and the struts attach
  to the triangular platform. The platform connects to the rotating frame through **rods with pivot
  flexures at both ends**. Each rod carries only axial load, so each cell sees a single force. This is
  the stated way of keeping mechanical interaction low (p.2).
- Pitch: a parallelogram mechanism with a lead screw drives the tail strut, range -20 to +30 deg.
  Yaw: worm gear on the fixed frame, range +/-180 deg. Both use step motors under PC control (p.2).
- Cell layout (Fig.3): vertical cells ZPD and ZPL (left and right, at +/- l laterally, offset +f
  longitudinally) and ZZ (on the centreline, at -2f). Horizontal drag-direction cells XD and XL
  (at +/- n laterally). One side-force cell YY. O is the model reference point and O1 the balance
  reference point, separated vertically by c1 (for the drag cells) and c2 (for the side cell).
- Load resolution (Eq.1, p.2):
  - X = XD + XL
  - Y = YY
  - Z = ZPD + ZPL + ZZ
  - L = c2*YY + l*ZPD - l*ZPL
  - M = -c1*XD - c1*XL + f*ZPD + f*ZPL - 2f*ZZ
  - N = -n*XD + n*XL
  
  Pitching moment is the difference between the vertical cells, combined with drag times the strut
  height c1. **The large transfer distance c1 multiplies drag into pitching moment**, so any drag error
  shows up in M.
- Fig.4 (p.3) shows three CAD renderings. They highlight in red which rods and cells are loaded under
  rolling moment, pitching moment, and drag.

## 3. Load ranges (Table 1, p.2; Table 2, p.4)

| Component | Design load | (US units) |
|---|---|---|
| Lift Z | 150 N | 33.7 lbf |
| Drag X | 100 N | 22.5 lbf |
| Side Y | 75 N | 16.9 lbf |
| Pitch M | 7 N*m | 62 in-lbf |
| Roll L | 7 N*m | 62 in-lbf |
| Yaw N | 7 N*m | 62 in-lbf |

Cell ranges: the vertical cells (ZPD, ZPL, ZZ) are 200 N each and the horizontal cells (XD, XL, YY)
are 100 N each (p.3, p.4 Table 2).

For comparison, our ranges are N = 15 lbf, A = 2 lbf, m = 10 in-lbf. Their drag range is **about 11x
ours** and their pitch range about 6x ours.

## 4. Element geometry and material (p.3 Fig.5; p.4 Eq.2-4)

- **Single-force cell (Fig.5):** a rectangular closed frame (a "binocular"/ring-frame cell). F is applied
  axially through a hole or stud at top and bottom. Inside the window there are two thin bending beams
  of length Lt, width b and thickness h. The beams act as guided (S-bending) beams. Gauges 1 and 2 sit at
  one end of the inner beam surface and gauges 3 and 4 at the other end, so two gauges are in tension and
  two in compression. The photo shows the cell in a loading fixture with a load stud on top.
- Bending stress as printed (Eq.2): sigma_b = (1/2 * F * Lt) / (b h^2 / 6), and eps = sigma_b / E.
  (The guided-beam end moment per beam with 2 beams would be F*Lt/4. Check this constant before reusing
  it. Our `balance_sizing.py` uses (A/2)*L/2.)
- **Full-scale design strain:** horizontal cells 966.7 ue (Eq.3), vertical cells 920.5 ue (Eq.4).
  These are about 2x the 500 ue target in our script.
- All six cells use the same design. Only the measuring-section dimensions change with range (p.3).
- Material: **ARMCO PH 13-8 Mo stainless steel**, chosen for its strength and corrosion resistance. The
  authors say VTI experience shows it is one of the best balance steels and that **material choice
  strongly affects hysteresis, creep and repeatability** (p.3-4).

## 5. Gauges, bridges and electronics (p.3-4)

- Each cell has one full 4-active-arm Wheatstone bridge, with 2 gauges in tension and 2 in compression
  placed close together for thermal compensation (Fig.5 bridge diagram, p.3).
- Gauges: **Vishay TK-06-S082R-350** for all cells. These are 350 ohm, K-alloy (Karma), self-temperature-
  compensated for steel (06), with a dual-grid "R" pattern. Selection followed Vishay TN-505-4 (p.4).
- Excitation: **6 V**. The material and gauges allow up to 20 V (per TN-502), and the lower value was
  chosen to limit self-heating (p.4).
- Output at FS: e1 = 11.6 mV for the horizontal cells (about 1.93 mV/V, consistent with GF = 2.0) and
  e2 = 11.97 mV for the vertical cells (Eq.5-6). Note that e2 implies k = 2.17, not 2.0, so either
  the strain or the output value is inconsistent in the paper.
- No DAQ, amplifier, filtering or ADC details are given. The paper says only that the cells are
  connected to a data acquisition system and that the motors are PC-controlled.

## 6. Calibration method and rig (p.4, Fig.6)

- Each load cell was calibrated individually **before** assembly, to **0.05% FS** (p.4).
- Balance calibration used manual dead weights applied at precise points relative to the balance
  reference centre, both positive and negative, at several stations. The rig was the VTI T-38
  calibration hall (p.1, p.4).
- **Calibration body:** two crossed beams with precisely located load points, mounted on the support
  struts in place of the model. Each component was loaded in at least 5 increments from zero to maximum (p.4).
- Data reduction is VTI's generalisation of Galway (NAE LR-600). It is related to the Single-Vector
  Force Calibration method (Parker et al., AIAA-2001-0170) and allows more than one composite load vector (p.4).
- Model: {e} = [C]{F}, a **linear 6x6 matrix** (6 terms per cell) fitted by least squares. Here {F} is the
  set of cell forces, not the aero components; the aero components then come from Eq.1 (p.5, Eq.7-8).
- **No combined loads** were used in this first calibration. The authors expect accuracy to improve
  when combined loads are added (p.5 Conclusion).

## 7. Accuracy and interactions (p.5, Eq.8, Fig.7, Tables 2-3)

- **Calibration matrix (Eq.8):** the diagonal terms are about 7.9e-6 (vertical cells) and about 1.85e-5
  (horizontal cells), in output units per N.
  - The largest off-diagonal terms are about 6.2e-7 (eZZ due to XL, about 8% of ZZ's own sensitivity)
    and about 5.9e-7 (eXL due to XD, about 3% of XL's own sensitivity).
  - Most other off-diagonal terms are 1e-8 to 2e-7, which is roughly 0.1-2%.
  - Conclusion: the rod/pivot decoupling is good but not perfect, and the matrix is needed.
- **Fig.7 (p.5):** six strips of Err (% FS) against applied load (% FS, about -140 to +140), one per cell.
  Horizontal lines mark the nominal accuracy band, and all residuals stay well inside +/-0.5% FS.
- **Table 2, per cell:**

  | Cell | Range | Max |Err| | Max |Err| | Std. dev. |
  |---|---|---|---|---|
  | ZPD | 200 N | 0.40 N | 0.198% FS | 0.056% FS |
  | ZPL | 200 N | 0.39 N | 0.195% FS | 0.064% FS |
  | ZZ | 200 N | 0.44 N | 0.222% FS | 0.080% FS |
  | XL | 100 N | 0.23 N | 0.226% FS | 0.082% FS |
  | XD | 100 N | 0.16 N | 0.162% FS | 0.039% FS |
  | YY | 100 N | 0.28 N | 0.281% FS | 0.084% FS |

  The checkout reused the same load set as the fit, so these errors are optimistic.
- **Table 3, composite components:**

  | Component | Range | Max error | Std. dev. |
  |---|---|---|---|
  | X | 100 N | 0.338% FS | 0.103% FS |
  | Y | 75 N | 0.374% FS | 0.112% FS |
  | Z | 150 N | 0.218% FS | 0.085% FS |
  | L | 7 N*m | 0.886% FS | 0.213% FS |
  | M | 7 N*m | 0.871% FS | 0.246% FS |
  | N | 7 N*m | 0.414% FS | 0.154% FS |

  The moment components are the worst because they are differences of large cell forces multiplied by
  arm lengths. Roll and pitch were only calibrated to about 50-60% of range.
- In our units, the drag error of 0.338 N equals 0.076 lbf, which is about **14 drag counts** on our
  qS = 5.48 lbf. That is **3.8% of our 2 lbf A full scale**.

## 8. Figure index

| Fig. | Page | Content |
|---|---|---|
| 1 | p.2 | Photo/CAD of the full balance with 12-item legend: model on main and tail struts, triangular platform, rods with pivot flexures, cells, rotating and fixed frames, pitch/yaw mechanisms, step motor |
| 2 | p.2 | Rendering of the model with lift, drag, side force and the three moments |
| 3 | p.2 | Schematic of the cell arrangement with lengths c1, c2, f, l, n and reference points O and O1 |
| 4 | p.3 | Three renderings showing loaded members (red) under roll, pitch and drag |
| 5 | p.3 | Photo of a cell in a load fixture; CAD of the frame cell with beam dimensions Lt, b, h; gauge positions 1-4; full-bridge diagram |
| 6 | p.4 | Two photos of the balance calibration setup in the T-38 calibration hall (calibration body on the struts, weight pans) |
| 7 | p.5 | Six residual-plot strips showing Err % FS against load % FS for each cell, with +/-0.5% lines |
| Tables 1-3 | p.2, p.5 | Design loads, per-cell accuracy, composite accuracy |
| Eq.8 | p.5 | Full 6x6 calibration matrix |

## 9. Relevance to our design

### Ideas that transfer to the internal sting balance (`balance_sizing.py`)

1. **Element type confirmation.** Their frame cell uses two guided beams with gauges at the beam ends.
   That is the same mechanics as our 2-plate Z-parallelogram axial flexure, with the same 4-arm
   +e/-e/+e/-e bridge and the same GF*eps*U output relation (our `bridge_mVV`). A closed rectangular
   frame like Fig.5 is a robust form for a stand-alone axial element. It could be EDM-cut as the axial
   section, with the end-moment constant checked first (see section 4).
2. **Strain level.** They run about 920-970 ue at FS (about 1.9 mV/V) in PH 13-8 Mo. Our 500 ue target
   in 7075 is conservative. Raising the axial plates toward about 700-800 ue would help the weak A
   signal, provided fatigue, creep and the overload stops allow it. They explicitly attribute hysteresis
   and creep behaviour to the material.
   - Option: make the balance from **17-4 PH H1025 or PH 13-8 Mo** instead of 7075-T651. Use the -06
     gauge STC, and consider K-alloy gauges for better creep and drift behaviour. Steel is about 3x
     stiffer, so a steel balance needs thinner sections for the same strain, which costs machining
     precision on our tiny A plates (0.025-in class).
3. **Rods with pivot flexures as load-path decouplers.** Each cell sees only axial force because the rods
   have flexure pivots at both ends. Internally, this argues for flexure-hinged guide or link elements
   that keep N and m out of the A gauges. That matters because our script flags N->A coupling from
   plate axial strain.
4. **Pre-calibrate the element before final assembly** (they reached 0.05% FS per cell). For a
   monolithic balance that is not possible, but an early bridge check is still worthwhile: a cantilever
   dead-weight check of each bridge before wiring the full harness.
5. **Calibration lessons.**
   - Use a crossed-beam calibration body with precisely located load points, and at least 5 increments
     in both signs.
   - **Include combined loads.** Leaving them out was their main accuracy shortfall: moment errors
     around 0.9% FS.
   - Do not quote accuracy from the same load set used for the fit.
6. Use **6 V excitation on 350 ohm gauges**. This matches our 5 V choice.

### External/platform balance as an alternative for our tunnel

The paper's tunnel is a good analogue: 0.4-0.6 m square section (15.7-23.6 in) at up to 50 m/s
(112 mph). Ours is 26.25 x 11.25 in at 70 mph.

**Pros**
- Size is not limited by the 2-in pod. The cells live under the floor, so they can be large, off-the-shelf
  or commercial (single-point or S-beam cells in the 5-25 lbf class), and no gauging inside the model
  is needed.
- The model pod can be simpler, and models are easy to swap.
- Cells sit out of the flow, so there are fewer thermal and flow effects on the gauges.
- 6 components are easy, and alpha/beta drives integrate naturally (as in their pitch -20/+30 deg and
  yaw +/-180 deg).
- Each cell can be calibrated individually.
- With the short height (11.25 in), floor struts stay short, about 5 in to the centreline.

**Cons**
- **Strut tare and interference** land directly in the drag measurement. Two struts, each about
  0.3-0.5 in across and 5 in long in the flow, can give drag comparable to our wing's minimum drag
  (only about 0.1-0.2 lbf). Shielding the struts with non-metric windshields is essentially mandatory,
  plus strut-tare runs (image or tare/interference procedure).
- **Accuracy scaled to our loads is marginal.** Their drag error is 0.34% of 100 N. With commercial
  cells sized for lift (about 15-30 lbf), drag resolution of a few hundredths of a lbf is hard. A
  dedicated low-range drag cell or flexure stage is needed.
- **Moment accuracy suffers from long arms.** Pitch is a difference of large forces and is coupled to
  drag through the strut height c1 (Eq.1). Their M error is 0.87% FS.
- **Mechanical complexity is high.** Their 6-component version needs a platform, 6 rods with 12
  flexure pivots, rotating and fixed frames, pitch and yaw mechanisms, a floor seal/labyrinth gap, and
  a pressure-balanced floor cut-out for the closed-return tunnel. That is roughly 3-5x the
  fabrication effort of one monolithic internal balance.
  - A **3-component platform** would be far simpler: 2 vertical cells plus 1 drag cell, a flexure-guided
    parallelogram platform, and a single strut with a tail pitch link. It is probably comparable in
    effort to the internal balance, with easier gauging (buy cells) but harder aerodynamic tares.
- **A sidewall (one-piece) balance**, which the paper notes is used for half-models (p.1), would require
  a half-span model or a long cross-flow support to the pod. That is a poor fit for an 18-in full-span
  wing in a 26.25-in-wide section.

**Verdict.** A platform external balance is credible at our scale and removes the hardest miniaturisation
problem (the A flexure in a 2-in pod). It trades that for strut-tare and interference corrections and
more machinery. For drag-polar quality data on a 2 lbf drag range, the internal sting balance remains
the better-resolution option. A 3-component floor platform with commercial cells and a shielded strut
is a reasonable fallback or prototype path.

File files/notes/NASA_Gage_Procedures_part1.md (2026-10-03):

# NASA TM-110327 "Recommended Strain Gage Application Procedures for Various Langley Research Center Balances and Test Articles" (T. C. Moore Sr., LaRC, March 1997) - Notes, Part 1 (PDF pages 1-47)

Reader scope: PDF pp. 1-47 (printed pp. 1-41). PDF pp. 48-94 are covered by a second set of notes (part 2). Those pages hold the rest of Class IV, Class V, and Addenda 1-4: gauge matching, the M-Bond 450 and M-Bond 200 bulletins, and the flame-spray photographs.

**Page numbering:** printed page N = PDF page N + 6. Below, citations read "p.N (PDF N+6)".
**Figures:** PDF pp. 1-47 contain **no figures, tables, or photos**. Every page is typed text (checked against the page images; the photographs are all in the addenda, PDF p.78 onward). The OCR text layer is good. Fixes to the OCR: "EA-g34" = Hysol **EA-934**; "+/-.O05mVN/A 100F" = **+/-0.005 mV/V per 100 deg F**; "C-891113-A" really is the custom Micro-Measurements gauge part number (confirmed on the image of PDF 12).

---

## 1. Page-by-page map (PDF 1-47)

| PDF | Printed | Content |
|---|---|---|
| 1 | - | Cover: TM-110327, March 1997 |
| 2 | - | Blank |
| 3-5 | i-iii | Table of contents, list of addenda, list of photos (Photos 1-15 belong to Addendum 4, the high-temperature flame-spray gauge, printed pp. 72-86) |
| 6 | - | Blank |
| 7 | 1 | Abstract (LaRC uses more than 10,000 gauges per year), introduction, explanation of "Application Class / Installation Type", and **general notes**. The procedures are for *new* installations, not regaging. Surface-prep materials "subject to change". **"Room temperature" means a part and air temperature of 72-80 deg F with RH never above 40%** |
| 8-11 | 2-5 | Index of procedures. Class I = balances (printed 6-15). Class II = transducers (16-28). Class III = composites (29-40). Class IV = above 700 deg F (41-49). Class V = unusual cases (50-58) |
| **12-16** | **6-10** | **Class I Type 1: standard LaRC 6-component balances, 0-200 deg F. THE PROCEDURE MOST RELEVANT TO US** |
| 16-22 | 10-16 | Class I Type 2: cryogenic balances (NTF), -275 to 150 deg F |
| 22-26 | 16-20 | Class II Type 1: LaRC transducers, 0-200 deg F (nearly identical to Class I Type 1) |
| 26-31 | 20-25 | Class II Type 2: cryogenic transducers |
| 31-34 | 25-28 | Class II Type 3: transducers at 200-450 deg F (M-Bond 450, RTV 3140 coating) |
| 34 | 28 | Class II Type 4: spaceflight transducers (no procedure given; use Types 1-3 as a guide) |
| 35-37 | 29-31 | Class III Type 1: Gr/Ep composites at room temperature (GA-2 or M-Bond 200, vacuum-pad clamping) |
| 37-39 | 31-33 | Class III Type 2: Gr/Ep from 250 deg F down to -452 deg F (M-610 at 40 psi, 250 deg F) |
| 39-41 | 33-35 | Class III Type 3: SiC-coated carbon composites at room temperature |
| 41 | 35 | Class III Type 4: metal-matrix composites at room temperature (Al/Ti matrix oxidizes quickly, so gauge right after prep; M-Bond 200 for short-term tests) |
| 41-43 | 35-37 | Class III Type 5: metal-matrix composites from -320 to 400 deg F |
| 43-44 | 37-38 | Class III Type 6: metal-matrix composites from 400 to 700 deg F (custom procedure only) |
| 44-46 | 38-40 | Class III Type 7: adhesive/polymer composites at room temperature |
| 46 | 40 | Summary for composites: review the test parameters with the engineer first |
| 47 | 41 | Class IV intro and Type 1: LARC-CKA1-1B high-temperature compensated gauge on Inconel/TMC, steps 1-3 (rest in part 2) |

---

## 2. Class I Type 1: Standard LaRC balance (0-200 deg F). Full detail (p.6-10, PDF 12-16)

Apparent-strain correction is made over **80-180 deg F**. Balances that will run at 200-300 deg F should follow Class II Type 3 instead (p.6, PDF 12).

### 2.1 Gauging materials (p.6, PDF 12)
1. Gauge: chosen by the designer. The usual choice is **Micro-Measurements custom C-891113-A**. The cryogenic version is C-891113-B (p.10).
2. Adhesive: **M-BOND 610** (Micro-Measurements), a solvent-thinned, heat-cure epoxy. PRTs are bonded with **Hysol EA-934**.
3. Wiring terminals: **MM CPF-25C, CPF-38C, or CPF-50C**, sized to the balance.
4. Insulation pads under the apparent-strain and zero-correction wires: etched 1-mil **Kapton**.
5. Gauge-to-terminal jumper: **AWG 40 silver-clad copper**.
6. Apparent-strain (temperature-zero) correction wire: **nickel**, length set by the correction needed.
7. Zero-offset correction wire: **Manganin** (Driver-Harris).
8. Intra-bridge (gauge to gauge) and inter-bridge wire: **AWG 30 (7/38), 32 (7/40), or 36 (7/44)**, 7-strand silver-clad copper with **Teflon** insulation. **Small balances may need solid AWG 40 or 42.**
9-10. Exit leads and connector: set by the designer or facility.
11. Solder: **MM 361A**.
12. Thermocouples: type **J, AWG 36**, Teflon-insulated. 13. PRTs: **HY-CAL EL-700T**.
14. Protective coating: **Gagekote #8** (JP Technologies).
15. Sleeving over exit leads: nylon or fiberglass.

### 2.2 Surface preparation (p.6-7, PDF 12-13)
1. Degrease the whole balance by vapor-degreaser rinse with **ENSOLV** (Envirotech).
2. Inspect under the microscope for surface flaws, cracked beams, and sharp edges.
3. Rinse with pure alcohol.
4. Mask around the gauge areas.
5. **Micro-sandblast the gauge areas with 50-micron Al2O3.**
6. Remove the masking and blow off the grit with dry shop air.
7. Repeat the ENSOLV and alcohol rinses. **Start installing gauges immediately afterwards.**

### 2.3 Gauge installation and cure (p.7, PDF 13)
1. Clean the gauges, the pre-trimmed terminals, and the pads with alcohol and dry them. Lay them **upside down on a clean glass plate**.
2. Brush **one coat of M-610 on the gauge undersides AND one on the balance surface**.
3. **Air-dry at least 10 min** at room temperature, defined as at least 72 deg F with RH at or below 40%.
4. Place the parts at their marked locations and cover them with **thin pressure-sensitive Teflon tape**.
5. Put **silicone-rubber pads** over the tape.
6. Clamp at a **constant, uniform 60 psi** with a suitable clamp.
7. Heat in an oven to **340 deg F at about 6 deg F/min**.
8. **Hold 1 h at 340 deg F**, then cool by opening the oven door.
9. Unclamp. Check under the microscope for position, alignment, glue-line voids, and foreign matter. **Position tolerance is typically +/-0.005 in from the drawing.** Replace any doubtful gauge.
10. **Several cure cycles are needed** to gauge every face. Re-sandblast and re-clean each later area just before its cycle.
11. **Post-cure: ramp at the same rate to 340 deg F, hold 2 h, cool, and inspect again.**

### 2.4 Wiring (p.7-8, PDF 13-14). Given as "good practice", not a fixed procedure
1. On a worksheet, record each gauge's resistance **to 0.01 ohm at the gauge solder dots**.
2. Remove oxide from the CPF terminals with a **hard rubber eraser**.
3. Solder the AWG 40 jumpers from the gauge dots to the terminals, following the NASA soldering handbook **NHB 5300.4(3A-1)**.
4. Remove flux with ENSOLV and a soft brush.
5. Re-measure each gauge **at its terminals**. This checks the jumpers and the solder joints.
6. **Insulation test for the wire itself:** submerge the wire in tap water and measure leakage to ground. It must be **> 10,000 Mohm (10 Gohm)**.
7. Strip and tin the intra- and inter-bridge wires carefully, inspecting for nicked strands before tinning.
8. **Make intra-bridge wires equal in length and resistance** wherever possible.
9. **Keep wires snug against the balance surface along their whole length. Never let wires span open areas of the balance. On lightly loaded balances, make sure the wires carry no part of the load on the measuring beams. Later, do not let the moisture coating bond wires to load-carrying beams.**
10. Plan the routing beforehand. **Never route a wire over an active grid or over the gauge jumpers.**
11. Clean off all solder residue.

### 2.5 Initial electrical checks (p.8, PDF 14)
1. Leakage to ground on every bridge must be **> 10,000 Mohm**, measured with a tester that applies **15 VDC (at 20 Mohm)**.
2. Record the electrical zeros **at the excitation that will be used in service**. Each zero should be **within +/-0.050 mV/V of the value calculated from the four measured gauge resistances**. This is harder to meet on small balances, where lightly loaded beams and fine wiring affect the zero.
3. The allowed zero tolerance is on the drawing. **The typical allowance is +/-0.4 mV/V.**
4. **Shunt each gauge mechanically** while watching the zero, to confirm the bridge is intact. The cryogenic section adds: do not use sharp probes, which dent the solder joints (p.12-13).
5. Hand-load each component to check its sensitivity. Also check that the zero returns after loading and unloading.

### 2.6 Elevated-temperature soak (p.8, PDF 14)
Soak the fully wired balance at **200 deg F for 4 h**. After it cools, re-check the zeros. **A shift greater than 0.010 mV/V means there is a problem to investigate.**

### 2.7 Apparent-strain (thermal zero) correction (p.9, PDF 15)
1. Place the balance horizontally in the oven with **-N facing up, supported only at the non-metric end**.
2. Cover it with a **non-contacting enclosure** so no airflow reaches it directly.
3. Tape a thermocouple with **aluminum tape** to the top of the aft shoulder, or use the balance's own aft TC/PRT.
4. Use the same excitation as the load calibration, and let the setup stabilize.
5-6. Start recording output against temperature at an 80 deg F setpoint. Wait until **drift is under 0.005 mV per 5 VDC per 5 min** and the balance is within **+/-2 deg F of 80 deg F**.
7. Set the oven to 180 deg F and heat to within 5 deg F of it, **at no more than 6 deg F/min**.
8. **Soak at least 15 min**; large balances need longer.
9. Cool back to within +/-2 deg F of the step 6 temperature.
10. Read each component's output at 180 deg F against the **return-to-room zero**.
11. **Add nickel wire to the appropriate bridge arm** to cancel apparent strain. **The typical tolerance is +/-0.005 mV/V per 100 deg F.**
12. Repeat the run.
13. Apply the moisture coating (section 2.8) and run a check.
14. Make another run for repeatability: **within +/-0.003 mV/V of the previous run over the whole temperature excursion**. That run becomes the final one. Give a final microscope inspection, then send the balance to calibration. Water-cooled balances get one more run with the cooling jacket fitted.

### 2.8 Moisture-proofing (p.10, PDF 16)
Applied after the apparent-strain run of step 12:
1. Flush with ENSOLV, then pure alcohol.
2. **Warm the balance to about 100 deg F.** While the surface is still warm (90-100 deg F), brush **Gagekote #8** over the gauges, jumpers, terminals, and the surrounding area. Coat thickness: **0.005-0.007 in**.
3. **Air-dry at least 20 min**, then brush a second coat. Then go back to step 13 above.

---

## 3. Class I Type 2: Cryogenic balance (p.10-16, PDF 16-22). Differences that matter or that are useful ideas

- Gauges are **matched for apparent strain** before installation (Addendum 1, see part 2). Matched gauges are cataloged and kept in individual pockets of a gauge organizer (p.11).
- The apparent-strain correction wire is **AWG 40 copper** rather than nickel. **"Axial differential compensation sensors"** of nickel/alloy 99 (Driver-Harris) correct thermal-gradient "loop error" on the axial bridge (p.10, 13-14).
- **Before wiring, mask each gauge and lightly micro-sandblast around the gauges and terminals** so the moisture coating bonds better (p.12, PDF 18). Also used in Class II Types 2 and 3.
- Hardware: dry-GN2 purge of the sting at about **4.5 SLPM** during thermal runs; Loctite 222 on the connector screws; Dow-Corning RTV-3140 between connector and sting; a custom TFE convection shield (p.10, 13).
- Thermal runs: three PRTs (front, middle, rear) must agree within 3 deg F. Start at 70-75 deg F. Drift criterion is **< 0.005 mV per 5 VDC per 3 min**. Go to -270 deg F. Bridge power off at 0 deg F during warm-up (p.13-14).
- Coating is **M-COAT B**, 2 coats, **0.002-0.003 in** cured, each **air-dried 2 h**, applied **only at 75 deg F or above with RH under 40%**. It goes over solder joints and bare wire only, **never over the active grids**. After coating, the zero must be within **0.050 mV per 5 VDC** of the pre-coat zero and leakage still above 10 Gohm (p.14, PDF 20).
- Final verification: hot (150 deg F) and cold (-270 deg F) cycles, repeated until consecutive runs agree (p.14-15).
- **Final checks before calibration (p.15, PDF 21):**
  - Record the final zeros.
  - **Wet-brush leakage test:** flood the gauge and solder areas with tap water using a soft artist's brush and measure leakage to ground.
  - **Wet-brush "water effect on signal" test:** no spurious signal greater than **0.075 mV at 8 VDC** excitation (about 0.0094 mV/V). The 8 V is used only for this deliberately harsh test.
  - Record appearance under the microscope.
- Keep a **balance log book** recording every deviation, problem, and discussion with the designer (p.15).

## 4. Class II: Transducers (p.16-28, PDF 22-34)
- **Type 1 (0-200 deg F)** is essentially the Class I Type 1 procedure, word for word. Same materials, M-610 cure at **340 deg F / 1 h at 60 psi** plus a **2 h post-cure**, Gagekote #8 coating, 200 deg F / 4 h soak, and the same zero, leakage, and apparent-strain limits. One change: the transducer sits in the oven so its "load beams expand without constraint", and the TC goes as close to the beam as possible (p.18).
- **Type 2 (cryogenic)** mirrors Class I Type 2. It uses a type T AWG 30 TC (p.20-25).
- **Type 3 (200-450 deg F)** (p.25-28, PDF 31-34):
  - Gauge **J5K-06-S104P-350/DP**; **M-BOND 450** per MM bulletin (Addendum 2); solder **570-28R**.
  - Clamp at **50 psi** under CHR type C Teflon tape instead of the MJG-2 Mylar tape. Post-cure at **50 deg F above the maximum operating temperature**.
  - Soak at the maximum operating temperature for 2 h.
  - Coat with **RTV 3140, 0.025-0.035 in thick**, brushed on warm and cured overnight.
- **Type 4 (spaceflight):** no procedure; each part gets its own (p.28).

## 5. Class III: Composites (p.29-40, PDF 35-46). Points useful to a hobbyist
- **Room-temperature-cure option (Types 1, 3, 7):**
  - Use **M-Bond GA-2** (a room-temperature or mildly heated epoxy) or **M-Bond 200** (cyanoacrylate).
  - **M-Bond 200 is allowed ONLY when every test is finished within 6 weeks of gauging.** For long-term or repeated testing, use the epoxy (p.30, 34, 39). This is the key reliability warning against a cyanoacrylate-bonded balance.
  - GA-2 cure: **4 h at 100 deg F or 2 h at 125 deg F**; if the part can't be heated, **overnight at 80 deg F or above**. Type 7: 6 h at 100 deg F, 4 h at 125 deg F, or overnight at 72 deg F or above with RH at or below 40%.
  - Clamp with a **vacuum pad**.
- **Hinge-taping technique (p.30, PDF 36):**
  1. Mark alignment lines on the surface matching the gauge's alignment marks.
  2. Lay the gauge face-down on glass and apply **CHR type C Teflon tape** to its top.
  3. Transfer it to the part and align it.
  4. **Fold it back** on the tape hinge so the underside faces up.
  5. Brush adhesive on the gauge and on the surface.
  6. When the adhesive's viscosity is right, fold the gauge back down and clamp.
  This works with hand tools and is the practical way to place gauges inside a narrow window.
- Hand-sanding alternative to micro-blasting: **220-grit SiC paper** (p.29) or 280 grit (p.32).
- Gauge-wiring sequence for lead wires (p.30, PDF 36):
  1. Remove oxide from the pads with an eraser.
  2. Check the gauge resistance against its spec.
  3. Tin the pads.
  4. Strip and inspect the leads.
  5. Tin the leads.
  6. **Add a mechanical strain-relief loop near the gauge.**
  7. Secure the leads to the part, then solder.
  8. Remove the flux.
  9. Check total resistance.
  10. Leakage must be above 10 Gohm.
  Lead wire is typically a 3-conductor AWG 30 stranded silver-plated flat ribbon.
- **Type 2 (Gr/Ep, -452 to 250 deg F):** M-610 at **40 psi, 250 deg F for 3 h minimum, then a 275 deg F / 2 h post-cure** (p.32, PDF 38). This shows that **M-610 can be cured well below 340 deg F** with a longer hold. Coarse surfaces get an EA-934NA basecoat cured 4 h at 275 deg F (p.31).
- Coatings:
  - **M-Coat A** goes on solder joints and exposed wire only, as oxidation protection in a lab environment (p.31).
  - Coatings stiffen thin parts: "**reinforcing effect on thin surfaces**" is listed as a factor when choosing a coating (p.33, PDF 39). This is relevant to our 0.025 in plates.
- **Type 4 (Al/Ti metal matrix, p.35):** aluminum oxidizes fast, so **gauge immediately after surface prep**.
- **Type 5 (p.35-37):**
  - **Clean by scrubbing with M-Prep Neutralizer 5A** (ammonia-based).
  - Solder: 361A up to 300 deg F, **430-20S** up to 400 deg F.
  - Coating: GE RTV-159 about 0.030 in up to 400 deg F, or thin M-Coat B for cryogenic only. **Dry-N2 purge can replace a moisture barrier.**
  - Post-cure 350 or 450 deg F for 2 h, depending on test temperature.

## 6. Class IV Type 1 start (p.41, PDF 47)
High-temperature (up to 1500 deg F) **LARC-CKA1-1B** half-bridge compensated gauge (JP Technologies) on Inconel 100 and Beta 21S TMC. It uses an Al2O3 flame-spray (Rokide) or plasma-spray basecoat, a Nextel 312 thermal blanket, Hoskins 875 AWG 25 leads, and Inconel strapping. Steps:
1. Degrease with MM FTF-1.
2. Mask an open area of **0.6 x 0.7 in** with 3M #64 fiberglass tape.
3. Micro-blast with 50-micron Al2O3.

Thermal cycling to at or above the maximum temperature improves first-cycle data. **Not relevant to our balance.** Continued in part 2.

---

## 7. Condensed installation procedure for OUR balance (7075-T651, 12 x 350-ohm STC-13, 3 full bridges, 5 V)

This is based on Class I Type 1 (p.6-10). Hobbyist substitutions are marked **[SUB]**.

**Environment:** work at **72-80 deg F, RH at or below 40%** (p.1, PDF 7). [SUB] Use a small dehumidified room or an air-conditioned day. Do not bond on humid days.

**A. Gauges and materials**
- Gauges: MM **EA-13 or CEA-13 series, 350 ohm, 0.062 in grid** (for example 062AP or 062UW), from **one lot**.
  - Before installation, measure every gauge to 0.01 ohm with a 4-wire meter and **pair the closest values into each bridge**. This is a simplified form of LaRC's matching (p.11; Addendum 1).
  - Choose **pre-attached-lead or open-tab gauges with tabs pointing AWAY from the flexure root.**
- Adhesive: **M-Bond 610** (closest to LaRC) or, as a simpler alternative, **M-Bond 600 or AE-10**.
  - **Do NOT use M-Bond 200 for a balance meant to be used over many months.** LaRC limits it to tests completed within 6 weeks (p.30).
- Terminals: CPF-25C (the smallest LaRC uses) or MM CPF/CEG solder-terminal pads.
- Wire:
  - Jumpers: AWG 36-40 solid copper (MM 134-AWP or 134-AQP).
  - Intra-bridge: AWG 32-36 stranded Teflon (MM 326-DTV or 330-FTE type).
  - Exit lead: shielded 4- to 6-conductor cable.
- Solder: MM 361A-20R (or ordinary 63/37 rosin-core). Flux remover or isopropyl alcohol.
- Coating: [SUB] **MM M-Coat A** (air-dry polyurethane) or **M-Coat D**, or Gagekote #8 if you can get it. Two thin coats.

**B. Surface preparation (p.6-7)**
1. Deburr. **Break every sharp edge near a gauge.**
2. Degrease. [SUB] Use **MM CSM-2 degreaser or acetone** instead of the ENSOLV vapor degreaser.
3. Inspect under a loupe or stereo microscope for tool marks and cracks, especially at the 0.025 in plate roots.
4. Mask with tape. Abrade the gauge area. [SUB] Instead of 50-micron Al2O3 micro-blasting, use **wet-abrade with M-Prep Conditioner A (mild phosphoric acid) on 320-400 grit SiC paper**, then cross-hatch lightly. Use a hand micro-blaster (airbrush-type sand eraser) if available.
   - **Inside the 0.75 in axial window, use folded paper on a thin stick or a strip of abrasive cloth. Do not gouge or thin the 0.025 in plates.** Every 0.001 in removed changes the plate bending strain by about 8%.
5. Neutralize with **M-Prep Neutralizer 5A** (LaRC uses this on aluminum-matrix parts, p.36), then wipe with alcohol.
6. **Bond immediately.** Aluminum oxidizes quickly (p.35).

**C. Layout**
- Burnish layout lines lightly, outside the grid area.
- LaRC holds **+/-0.005 in position** (p.7).
- On the necks:
  - Two gauges sit side by side on a 0.50 in face. Center them symmetrically about the neck centerline so side-force bending cancels.
  - Place them at the same x-station top and bottom.
  - Put the solder terminals on the shoulders, **off the 0.60 in flexing neck**.

**D. Bond and cure (p.7)**
1. Clean gauges and terminals and lay them face-down on glass. Pick up each with Teflon tape. Use the **tape-hinge method** (p.30) to position it, fold it back, apply adhesive, and fold it down.
2. Brush M-610 on the gauge and on the part. Let it **dry 10 min or more**. Lay the gauge down.
3. Build the stack: Teflon tape, then a silicone-rubber pad, then a backing block, then a clamp.
   - Pressure: **LaRC uses 60 psi** (p.7). [SUB] Use a spring clamp or MM GT-14 spring clamp, sized as pressure x pad area. For example, a 0.25 x 0.35 in pad needs about 5 lbf.
4. Cure. LaRC's schedule is **ramp at 6 deg F/min to 340 deg F, hold 1 h, cool in the oven, then post-cure 340 deg F for 2 h** (p.7).
   - [SUB] Use a **toaster or convection oven** with an independent thermocouple taped to the balance.
   - **See the 7075 temper flag (section 8, item 4)** before using 340 deg F.
5. Remove the clamp and inspect under magnification for voids, edge lift, and alignment.
6. Re-prep each later face just before bonding it (p.7, step 10).
7. Cure-cycle plan:
   - Cycle 1: neck tops.
   - Cycle 2: neck bottoms.
   - Cycle 3: both axial plates together (see section 8).
   - Then one post-cure for everything.

**E. Wiring (p.7-8)**
1. Record each gauge's resistance at the gauge to 0.01 ohm.
2. Remove oxide from the terminals with an eraser.
3. Solder the jumpers (gauge to terminal), leaving a **small strain-relief loop**.
4. Remove the flux. Re-measure at the terminals.
5. **Complete each bridge on the balance**, using equal-length intra-bridge wires (p.8). Only 4 wires per bridge, or 6 with remote sense, then leave the metric part.
6. **Wires must lie flat in grooves or be tacked to non-flexing surfaces. They must never span the axial flexure gap or a neck as a free wire, and must never carry load** (p.8, item 9).
7. **Never route wire over a grid or a jumper** (p.8, item 10).
8. Clean all residue.

**F. Electrical checks (p.8)**
1. Leakage to ground: **> 10 Gohm at 15 VDC**.
   - [SUB] A 15 V supply in series with the bridge-to-balance path and a DMM on its 10 Mohm voltage range. The DMM reading V = 15 x 10M/(10M + R_leak). **R_leak = 10 Gohm gives about 15 mV.** A reading below about 15 mV passes.
   - A hobby insulation tester also works.
2. Zero at 5 V excitation:
   - It should be within **+/-0.05 mV/V of the value calculated from the measured arm resistances**.
   - Overall zero within **+/-0.4 mV/V** (typical). Trim a large offset with Manganin wire or in the amplifier or software.
3. **Mechanical shunt check of each gauge:** press near the grid with a blunt tool, not a sharp probe (p.12-13), and watch for a sign-consistent response.
4. Hand-load each component (N, A, m). Check sensitivity and return to zero.

**G. Stabilization and thermal checks (p.8-9)**
1. Soak **200 deg F for 4 h**, wired (p.8).
   - **Zero shift must be at or below 0.010 mV/V.** That is about 1% of our roughly 1 mV/V full scale. A larger shift means a bad bond or joint.
   - [SUB] Use the same oven, holding temperature below the solder and wire-insulation limits.
2. Apparent-strain run:
   - Place the balance -N up, supported at the sting end, inside a **cardboard or foil enclosure**.
   - Run 80 to 180 deg F (or 75 to 130 deg F, which better spans tunnel heating), ramping **at no more than 6 deg F/min** with a **15 min or longer soak**.
   - Target **0.005 mV/V per 100 deg F or less**.
   - [SUB] Rather than nickel-wire trimming, **mount a thermistor or RTD on the balance and correct the residual apparent strain in software**. STC-13 gauges on 7075 (CTE about 13 ppm/deg F) give a small residual.
3. Repeat the run. Two consecutive runs should agree **within 0.003 mV/V** (p.9).

**H. Moisture-proofing (p.10)**
1. Clean with alcohol.
2. **Warm the part to about 100 deg F.** Brush **2 thin coats, 20 min or more apart.**
   - Use Gagekote #8 at 0.005-0.007 in total, or M-Coat A.
   - On the axial plates, keep the coat **thin and identical on both plates**, and **do not let it bridge a plate to a rail or a wire to a beam** (p.8, item 9; p.33).
3. Re-check: zero shift from coating **at or below 0.05 mV per 5 V** (p.14), and leakage still above 10 Gohm.
4. **Wet-brush test** (p.15): brush tap water over the gauges.
   - Leakage must stay above 10 Gohm.
   - Spurious output must be **at or below 0.075 mV at 8 V excitation** (about 0.0094 mV/V; with our 5 V, keep it at or below about 0.047 mV).
5. Re-run the apparent-strain check with the coating on.

**I. Documentation:** keep a log book (p.15). Record:
- Gauge lot and resistances.
- Cure cycles and temperatures.
- Zeros at every stage.
- Leakage readings.
- Deviations.

---

## 8. Flags that affect our geometry and design (balance_sizing.py)

1. **Clamping inside the 0.75 in axial window.** LaRC cures under **60 psi through silicone pads** (p.7). The 0.025 in x 0.75 in x 0.75 in plates are very flexible: k_ax is low, and a 5 lbf clamp load on one plate face would bend or yield it.
   - **Clamp the two inner-face gauges in one self-reacting stack:** plate A, gauge, Teflon, rubber pad, rigid spacer, rubber pad, Teflon, gauge, plate B, with **backing blocks on the outer faces of both plates**, squeezed by one small clamp.
   - Window budget: 2 x (tape ~0.003 in + rubber pad ~0.06-0.10 in) + spacer. **0.75 in is enough for the pads, but tweezers, tape-hinge handling, a soldering tip, and an inspection loupe all need access.** Plan for **0.75 in as a practical minimum**. Do not shrink the window. Consider making the window open on both sides in y, with no side webs, for access.
   - Alternatively, **put the axial gauges on the OUTER faces** of the plates, which gives free access. Grid strain at a given distance from the root is the same in magnitude with the sign reversed, so bridge arms just swap.
2. **Gauge near the plate root (g_off = 0.06 in).**
   - A 0.062 in grid has backing that extends past the grid end. The end-tab margin is typically about 0.03-0.05 in (check the MM data sheet for the chosen pattern). The grid center therefore cannot sit closer than about 0.06-0.08 in plus the root-fillet radius.
   - The backing must lie flat, not up the fillet, and the **tabs must point away from the root**.
   - With +/-0.005 in placement tolerance (p.7) and a steep strain gradient near the root, expect bridge-to-bridge sensitivity spread. Calibration absorbs it, but the **plate-to-plate mismatch also drives the N-to-A interaction** that the script estimates at 2% mismatch.
   - Consider moving g_off to about 0.08-0.10 in and recomputing t_p and strain.
3. **Terminal and wire space.**
   - CPF terminals and jumpers need room **off the flexing elements** (p.6-8). The 0.60 in necks have no room for terminals next to a gauge of about 0.2 in backing length; put the terminals on the shoulders or rails.
   - The forward-neck bridge wires must cross the axial flexure to reach the sting. **LaRC forbids spanning open areas and letting wires carry load** (p.8). For our 2 lbf full-scale axial force on a compliant flexure, that matters a lot.
   - Provide a **wire channel or groove along the side of the axial section** and use the finest practical wire (AWG 36-40) with a slack loop. Complete the forward bridge locally so only 4-6 wires cross.
   - Expect wire-crossing hysteresis to show up in the A calibration.
4. **Heat cure versus 7075-T651 temper.**
   - LaRC's M-610 schedule is **340 deg F x 1 h per cycle plus a 2 h post-cure** (p.7). With 3 or more cycles, that is about 5 h or more at 340 deg F.
   - 7075-T6 is aged at about 250 deg F. Repeated exposure at 340 deg F begins **over-aging, moving toward T7x, which lowers yield strength** (an engineering judgment, not stated in this document; LaRC balances are usually maraging or PH steel).
   - Use **the lower-temperature, longer-hold M-610 schedule**. This document shows M-610 cured at **250 deg F for 3 h at 40 psi, with a 275 deg F post-cure** (p.32, PDF 38). Also see the MM M-610 bulletin.
   - Or use a room-temperature or low-temperature epoxy (AE-10, M-Bond 600 at its lower schedule).
   - In either case, **re-check the stress margins in balance_sizing.py** with a derated yield strength if 340 deg F is used.
5. **Coating stiffness on thin plates.** A heavy RTV coat (0.025-0.035 in, p.28) would be comparable to the 0.025 in plate thickness and would add stiffness and hysteresis. **Use only a thin coat (0.005 in or less) and keep it identical on both plates** (p.33 "reinforcing effect on thin surfaces").
6. **Zero and thermal budgets versus our signal.**
   - Our full-scale output is about 1 mV/V (5 mV at 5 V). LaRC's typical **+/-0.4 mV/V** initial zero is up to 40% of full scale, so check the amplifier offset range.
   - The soak criterion of **0.010 mV/V** is about 1% FS.
   - The apparent-strain tolerance of **0.005 mV/V per 100 deg F** gives about 0.1% FS for a 20 deg F tunnel temperature rise. Our 0.05% FS resolution target needs a **balance temperature sensor plus software correction**, or a nickel-wire trim.
7. **Excitation.** LaRC sets the zero and thermal checks at the service excitation (p.8). Our 5 V on 350 ohm gives about 18 mW per gauge, which is fine for aluminum. Run all checks at 5 V.

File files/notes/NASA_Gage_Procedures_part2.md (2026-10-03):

# NASA TM-110327 (Moore, March 1997) "Recommended Strain Gage Application Procedures for Various LaRC Balances and Test Articles" — Part 2 (PDF pages 48–94)

Page numbering: "p." = PDF page. Printed page number = PDF page − 6 (e.g., PDF p.58 = printed "-52-").
Pages 78–93 are scanned photos / blank; text pages were OCR'd and checked against page images.

## Bottom line for our balance

**None of pages 48–94 shows a balance gauge layout, bridge wiring diagram, or temperature-compensation procedure for a balance.** That material, if it is in this report, is in pages 1–47 (the other reader's range). This section covers:
- the end of Application Class IV (high-temperature gauges on titanium-matrix composites (TMC), C/C and ceramics, flame-sprayed),
- Application Class V (unusual materials: Al-Li, the inside of NTF model cavities, Ti/Al, polymer composites),
- a LaRC memo on **matching gauges for four-active-arm cryogenic balance bridges**,
- reprinted Micro-Measurements instruction bulletins for **M-Bond 450** and **M-Bond 200**,
- Addendum #4 (a high-temperature LaRC-CKAI-1B gauge install with 15 photos), and the SF-298 page.

The parts that apply to us are the **wiring and checkout steps**, the **acceptance numbers** (insulation leakage >10,000 MΩ, gauge resistance logged to 0.01 Ω, a 0.5 Ω drift rejection rule, bridge zero consistent with arm mismatch), the **adhesive cure schedules** (AE-10 room/low-temperature cure; M-Bond 450 hot cure; M-Bond 200 limits), the **moisture-coating practice** (RTV kept off the active grid), and the **gauge-matching idea** for 4-arm bridges.

---

## Page-by-page summary

### p.48–49 (printed 42–43): Class IV, Installation Type 1 (continued). LaRC compensated high-temperature gauge on TMC
- Flame-sprayed Al2O3 (Rokide) installation. Prep: micro-sandblast with 50 µm Al2O3, then coarse blast with #30 SiC. Optional plasma-sprayed basecoat ~0.001" applied within 30 min of blasting, then Rokide to a ~0.003" total basecoat.
- Active and compensating gauge pair. Check resistance after placement (Step 11). Initial bond with Norton SA rods. Remove carrier tapes and dress ridges under a microscope. Final coat gives a completed installation about **0.015" thick**.
- Optional "window-frame" Al2O3 border (0.030" gap) so the active and compensating elements stay at the same temperature when there is airflow or fast heating. Thermal blanket: 0.010" Nextel 312 with a 0.005" Al2O3 top coat, held by spot-welded straps or ceramic cement.
- Step 22: final microscopic inspection, plus a check of **gauge resistance and resistance to ground**. Lead attachment is by spot welding (no details given).
- *Relevance to us:* none for the process. The only transferable idea is that the active and compensating elements must see the same temperature (see the thermal notes below).

### p.50–51 (printed 44–45): Class IV Type 2. JP Technologies NZ-2104-120L free-filament foil gauge on Beta 21S TMC
- Leads: Hoskins 875, AWG 25, 3-conductor, with Nextel sleeving and overbraid. Inconel strap hold-downs.
- Same blast and flame-spray sequence. Extra carrier strips (~0.030" wide at 0.050" spacing) stop the convolutes from buckling. Resistance is logged on **Form FL-1**.
- **Acceptance rule (p.51, Step 16): if gauge resistance changes by more than 0.5 Ω between the Step-15 check and the pre-lead check, replace the gauge.**
- p.50 notes that Addendum #4 (p.75–92) has the detailed write-up with photos.

### p.52–55 (printed 46–49): Class IV Types 3 and 4. SiC-coated carbon/carbon and coarse ceramic composites
- Gauges must have **at least 1/4" active grid length and 2-mil wire** (foil is excluded). Short or thin grids fail at seams in the SiC coating, and gauges ≥1/4" long reduce scatter in the measured modulus.
- Lead hold-down on ~3/8" dia. blasted spots: an Omega CC cement collar on the lead (225 °F 15 min + 300 °F 1 h), then LEX-10 (0.001", air-dry 1 h, 300 °F 1 h). Omega CC is used because it has higher leakage resistance than LEX-10 and stops LEX-10 from corroding the Hoskins 875 leads.
- Type 4 basecoat: LEX-10 at ~0.002" per layer (air-dry ½ h, 225 °F ½ h, 300 °F 1 h), repeated as needed and honed, then ~0.002" plasma-sprayed Al2O3.
- p.55 contains only the closing note on lead connection (spot welding, no details).
- *Relevance to us:* none.

### p.56–58 (printed 50–52): Class V Type 1. Aluminum-lithium, room temperature to −320 °F, **no elevated-temperature cure allowed**
- Gauges: **CEA series for room temperature**, SK/WK for cryogenic. Adhesive **M-Bond AE-10**. Terminals CPF-25C/38C/50C. Jumpers AWG 38 silver-clad copper. Leads typically 3-conductor flat AWG 30 (Teflon insulation for cryogenic use). Solder 361-A.
- Surface prep: wipe with ENSOLV (never wipe back into an area already cleaned), microscopic inspection, wipe again with ENSOLV, mask and micro-blast with 50 µm abrasive, ENSOLV, then alcohol. **Start bonding immediately after the final wipe.**
- **Methyl-cyanoacrylate (including M-Bond 200) did not give enough bond strength on Al-Li**, as found in LaRC and Marshall testing. AE-10 was verified to 15,000 µε.
- **AE-10 cure (p.57):** coat both the gauge and the surface. Cover with thin Teflon tape and a silicone-rubber pad. Clamp at **15 psi**. Hold at **100 °F for at least 4 h**, or overnight at **80 °F minimum** if 100 °F is not allowed. Inspect for alignment, voids in the glue line, and debris. If a second cure cycle is needed for more gauges, blast and prep the remaining sites again.
- **Wiring good practice (p.57–58), applicable to us:**
  1. Record each gauge's resistance **to two decimal places at the solder dots**.
  2. Clean oxide off CPF terminals with a hard rubber eraser.
  3. Solder the jumpers (per NASA NHB 5300.4(3A-1)).
  4. Remove flux with a brush and Borothene.
  5. **Measure resistance again at the terminals** to confirm the jumpers and joints are good.
  6. Strip and tin all intra- and inter-bridge wires, and inspect for nicked strands before tinning.
  7. **Make intra-bridge wires equal in length and resistance.**
  8. Plan routing ahead. **Never run wires over active grids or jumpers.**
  9. Clean off all solder residue.
  10. Check the total resistance at the end of the leads.
  11. **For bridges, confirm the zero is consistent with the arbitrary resistance differences of the four gauges.**
  12. **Leakage to ground > 10,000 MΩ (10 GΩ).**
- Moisture-proofing (p.58): no single recipe. The coating is chosen for the temperature range, the moisture exposure, the **"reinforcing effect on thin surfaces to be strained,"** and how long the test runs.

### p.58–60 (printed 52–54): Class V Type 2. Gauges inside wind-tunnel model cavities (NTF, maraging steel, −275 °F to 180 °F), covered with body filler
- Gauge **WK-06-060BN-350 with option W** ("works well"). Adhesive **M-Bond GA-2** (preferred) or AE-10. Leads 3-conductor stranded AWG 30 silver-plated copper. Solder 361-A.
- GA-2 cure: air-dry the coated parts ≥5 min, Teflon and rubber pad, **10 psi**, then **≥6 h at ≥125 °F** (or 4 h at 150 °F). **Post-cure 8 h at ≥125 °F** (or 6 h at 150 °F, or 2 h at 200 °F) before filling the cavity.
- Wiring checks are the same as above, plus **etching (Tetra-Etch) any Teflon leads that will be potted**.
- Cavity fill: Insta-Pak 200 foam (1:1 by weight), set 2 h, trimmed to about 1/16" over the gauge. Then Hysol 9309 at about 1/32", cured ≥4 h at ≥75 °F. Then Hysol 9309 with S-100 CarboSpheres (1.5:1 spheres to adhesive by weight) to fill, and sand to contour. Record final electrical checks.
- *Relevance to us:* useful if gauges are ever placed in the wing or pod. The foam layer keeps the hard filler from loading the gauge.

### p.60–62 (printed 54–56): Class V Type 3. Titanium/aluminum alloys, −300 °F to 650 °F (not validated)
- WK gauges, BLH TL-56 terminals, **BLH PLD-700** adhesive (manufacturer's cure, then **post-cure 700 °F for 30 min**). Leads 326-GJF. Gold-alloy solder spheres (81.5Au/8.5Ag/10Ge, melting at 770 °F). Thermocouple INC-E-MO-062.
- Wiring: record resistance to two decimals at the terminals and again at the end of the leads. Leakage **>10 GΩ**.
- **Moisture-proofing (p.62):** clean with alcohol. Apply **GE RTV-159 about 0.050" thick over the terminals, solder joints and ribbons, and keep it off the active grid**. Apply with the part and the RTV at **≥72 °F and ≤40 % RH**. **Air-cure overnight** before testing. Keep RTV low over wiring so it does not crack in cold excursions. Lightly micro-blast the RTV sites first.

### p.62–64 (printed 56–58): Class V Type 4. Adhesive/polymer composites to 450 °F (adhesive cure limited to 250 °F)
- WK gauges, **M-Bond 600**, CPF terminals. Leads AWG 30 7/38 silver-plated copper with Teflon insulation. Solder 570-28R.
- Optional M-Bond 600 basecoat: air-dry 10 min, **30 psi**, ramp to 250 °F over ≥30 min, hold 1 h, then lightly blast.
- Gauge bond: air-dry 10 min, CHR type C tape, rubber pad, **30 psi, 250 °F for 2 h. Do not post-cure** (composite temperature limit).
- Wiring (p.63–64): check gauge resistance against the manufacturer's spec. **Provide mechanical strain-relief loops in both the gauge ribbons and the lead wires near the gauge.** Inspect stripped wire for nicks. Remove flux. Check the end-of-lead resistance. **Leakage >10 GΩ.**
- Moisture: usually none needed. If required, **3140 RTV or RTV-159**.

### p.65–68 (printed 59–62): LaRC memo, 18 Apr 1994, "Matching Cryogenic Strain Gages" (T. Moore)
- Problem: each gauge has its own apparent-strain (thermal output) curve. If four gauges are picked at random for a **four-active-arm bridge**, their mismatch shows up as bridge thermal output. The effect is larger at cryogenic temperatures.
- Method: temporarily bond **16 gauges from one type and one lot** (MM C-891113-B) to a matching disc with **M-Bond 200**. Wire each for **3-wire quarter-bridge** readout (AWG 40 jumpers, equal length and resistance; AWG 32 silver-clad Teflon leads). Run them through a temperature cycle and record each gauge's apparent-strain curve.
- **Fig. 1 (p.68), gauge matching disc:** a 4" dia. × 1" thick disc carrying two Kapton strips (0.2" × 2.5" × 0.002") and 16 CPF-38C terminals bonded with M-Bond 610. There are 8 SK-series gauges on each side of a central type-T thermocouple.
- Removal: soak at **170 °C for 2 h**. The M-Bond 200 breaks down and the gauges lift off. Then clean with Inhibisol, pumice (S.S. White #3), ammonia neutralizer plus hot water, and 200-proof alcohol. Inspect under a microscope.
- Pre-test check (p.67): excitation reads 5.000 V, each channel reads **within ±0.005 V** on the DAS, temperature reads 1 mV/°C. Turn off excitation once the part warms back to −10 °C, so condensation does not short the gauges.
- **Matching criteria (p.67):** gauges are grouped in fours by (1) peak output over the temperature excursion, (2) loop (difference between the cooling and warming runs at the same temperature), and (3) nonlinearity. **Each must be within ±0.015 mV at 5 V excitation (±3 µV/V).** Matched sets are catalogued for four-arm bridges in cryogenic transducers, **including wind-tunnel balances**.

### p.69–70: Micro-Measurements M-Bond 450 bulletin (reprint)
- Two-part solvent-thinned epoxy. Glue line can be as thin as 0.0001". Service: short term −452 to +750 °F, long term −452 to +500 °F. Elongation >5 %. Shelf life 6 months. **Pot life 6 weeks** after mixing. Let it stand **24 h after mixing** before use.
- Cure process:
  1. Coat the part and air-dry 10–30 min (75 °F, 50 % RH).
  2. **B-stage at 225 °F for 30 min** (ramp 5–20 °F/min). B-staged parts can be stored up to 1 week; re-dry 10 min at 225 °F if they may have picked up humidity.
  3. Transfer the gauge on MJG-2 Mylar tape and add no more adhesive.
  4. Lay on Teflon film, a 3/32" silicone pad and a backup plate. Clamp at **40–100 psi**.
  5. **Cure at 350 °F for 1 h.**
  6. **Post-cure ≥1 h at ≥50 °F above maximum operating temperature** (maximum 550 °F), stepping up 50 °F at a time with 60 min at each step.
- Do not use a general-purpose forced-air oven, because it spreads contaminants.

### p.71–74: Micro-Measurements bulletin B-127, "Strain Gage Installations with M-Bond 200"
- Cyanoacrylate, room-temperature cure. Normal range **−25 to +150 °F**. Apply at 70–85 °F and 30–65 % RH. Shelf life 9 months unopened (refrigerate unopened bottles, warm to room temperature before opening).
- **Humidity weakens the bond, so a protective coat is required. It embrittles with age and heat, and is not recommended for installations meant to last more than 1–2 years.**
- Surface prep:
  1. Degrease with CSM-1A, or GC-6 isopropyl alcohol on titanium and plastics.
  2. Dry-abrade with 220/320 grit, then wet-abrade with 320/400 grit and M-Prep Conditioner A.
  3. **Burnish layout lines with a 4H pencil on aluminum** (do not scribe).
  4. Scrub with Conditioner A until a clean swab stays clean, then wipe in one slow stroke.
  5. Apply Neutralizer 5A and wipe in one slow stroke, never back and forth.
- Bonding:
  1. Place the gauge face-down on clean glass with the terminal ~1/16" away, and pick both up on PCT-2A tape.
  2. Align the triangle marks, then lift the tape at about 45°.
  3. Apply catalyst thinly (wipe the brush about 10 strokes first) and let it dry ≥1 min.
  4. **Do the next three actions within 3–5 s:** put 1–2 drops of adhesive at the fold ½" outside the gauge area, make one firm wipe-down with gauze at about 30°, then hold thumb pressure for ≥1 min (several minutes if below 30 % RH or below 70 °F).
  5. Wait 2 min, then peel the tape back over itself.
- Figures 1–11 are hand-sketch illustrations of each step (p.72–74).
- Final installation (p.74): mask open-faced grids with PDT-1 tape before soldering, remove flux with RSK-1 rosin solvent, and choose a coating from Catalog A-110.

### p.75–92 (printed 69–71 plus photos): Addendum #4. LaRC-CKAI-1B compensated high-temperature gauge on Inconel 100 and Beta 21S TMC (Moore and Lamm)
- Expanded version of Class IV Type 1, with a 0.6" × 0.7" blast area and 3M #64 tape.
- **Photos #1–#15 (p.78–92, some printed upside down):** coupon with Al2O3 basecoat, gauge on carrier, first flame spray, tape removal, final spray, remasking for the window-frame border (#8–#11), completed elements, thermal blanket, strapped blanket, and the finished installation ready for leads.
- *Relevance to us:* none.

### p.93: blank. p.94: SF-298
NASA TM-110327, March 1997, WU 519-20-21-01, 90 pages. LaRC uses more than 10,000 gauges per year.

---

## What applies to our 7075-T651 3-component balance

### 1. Bridge wiring (necks and axial flexure)
- This range has **no balance wiring diagrams**; see the part-1 notes. The general rules it does give:
  - **Equal-length, equal-resistance intra-bridge jumpers** (p.57/58, p.60). On our necks, arms that are physically far apart (top and bottom faces) should get matched jumper lengths, so the jumpers do not add unequal resistance and unequal TCR (zero shift with temperature).
  - **No wires over active grids or jumpers** (p.58). This matters on the 0.50" neck faces and inside the 0.75" axial window. Plan terminal positions (CPF-type tabs on the rails or on the body, off the flexure) before bonding.
  - **Strain-relief loops** in gauge ribbons and leads (p.64). This is critical where leads cross from the live (model) side to the ground (sting) side of each flexure. A taut wire across the 0.025" axial plates would carry load and cause hysteresis.
  - 3-wire quarter-bridge wiring for testing single gauges (p.65). This is a handy way to check each gauge's response before closing the full bridges.

### 2. Temperature compensation
- The matching memo (p.65–67) confirms that **four-active-arm bridge thermal output comes from arm-to-arm mismatch in apparent strain**. LaRC solved it at cryogenic temperature by matching gauges in fours to within ±3 µV/V.
- For us (room temperature with tunnel heating of about 10–30 °F), **buy all 12 gauges from one lot**, with STC-13 to match aluminum's ~13 ppm/°F.
- A hobbyist version of the match is possible. Before final bridge closure, wire each bridge (or each gauge in quarter-bridge), then warm the whole balance slowly by 20–30 °F (oven or warm box, uniform temperature, no load) and log the zero drift. Compensate any remaining zero-vs-temperature with a small series resistor in the correct arm (the procedure itself should be in part 1).
- Keep both sides of each bridge at the same temperature (p.48–49, window frame and blanket). In a closed-return tunnel that warms as it runs, avoid airflow hitting one face of a neck. A pod or windshield over the balance helps.

### 3. Adhesive and cure. **Possible geometry and material conflict**
- **M-Bond 450 or M-Bond 600/610 at 350 °F (p.70) is the transducer-grade choice, but 7075-T651 is aged at about 250 °F.** One hour at 350 °F, plus post-cure steps, starts to over-age it. That means some loss of yield strength (it moves toward T73) and possible distortion of the 0.025" plates if they are not clamped evenly.
  - Our stress margins (SF on yield in `balance_sizing.py`) should allow for a few percent loss. Otherwise choose a lower-temperature cure such as M-Bond 610 at about 250 °F (check its datasheet) or AE-10.
  - Flag for the design team. Also check the 350 °F rating of the gauge backing (EA vs. CEA) and the solder.
- **AE-10 (p.57):** room or low-temperature cure, **15 psi, 100 °F for ≥4 h** (or overnight at ≥80 °F). It is hobbyist-friendly, does not affect the 7075 temper, and is validated on aluminum alloy (Al-Li) to 15,000 µε. It is a reasonable fallback, but expect more creep and hysteresis than with a hot-cured epoxy at our 500 µε level.
- **M-Bond 200 (p.71):** fastest option, but humidity-sensitive, embrittles, has a **1–2 year life**, and **was rejected by LaRC on Al-Li for bond strength** (p.57). Use it only for a prototype or proof balance, not the final transducer.
- Clamping needs a backup plate and a 3/32" silicone pad at 40–100 psi (p.70). Inside the 0.75" axial window, design a small clamp block or wedge that fits between the plates and supports the 0.025" plate from the opposite side so it does not bend.

### 4. Moisture protection
- Coat the terminals, solder joints and ribbons with **RTV 3140 or RTV-159 about 0.050" thick, kept off the active grid** (p.62, p.64). Apply at ≥72 °F and ≤40 % RH and cure overnight.
- **Geometry flag (p.58):** LaRC warns about the "reinforcing effect on thin surfaces." On our **0.025" axial plates**, the gauge, adhesive and any coating over the grid add stiffness and can creep. Keep coatings thin over the grid (or use a thin film such as M-Coat A/D on the grid and put RTV only on the joints), and apply them the same way on both plates and both faces. The calibration will absorb whatever reinforcement remains, as long as it is stable.
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

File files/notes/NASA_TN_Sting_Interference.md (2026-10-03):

# NASA TN D-4021 — Sting-Support Interference (Loving & Luoma, 1967)

**Title:** *Sting-Support Interference on Longitudinal Aerodynamic Characteristics of Cargo-Type Airplane Models at Mach 0.70 to 0.84*
**Authors:** Donald L. Loving and Arvo A. Luoma, NASA Langley Research Center
**Number/date:** NASA TN D-4021, July 1967 (60 PDF pages, scanned)

Page citations: "p. N" = printed page number; PDF page = printed + 2 (e.g. printed p. 5 = PDF p. 7; Fig. 1 = printed p. 14 = PDF p. 16).

**What this paper is not:** it is *not* a parametric study of sting diameter or length. It is a single-geometry tare study. It measures how one fixed, carefully designed sting interferes with three high-wing transport models that have strongly upswept aft fuselages. The general design rules (sting length, d/D, flare angle) are borrowed from its Ref. 1 (Love, NACA RM L53K12, 1954) and are only quoted here. For parametric d/D and L/D data, read Refs. 1–4 (Love; Tunnell, NACA RM A54K16a; Lee & Summers, NACA RM A57I09; Cahn, NACA Rept. 1353).

---
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

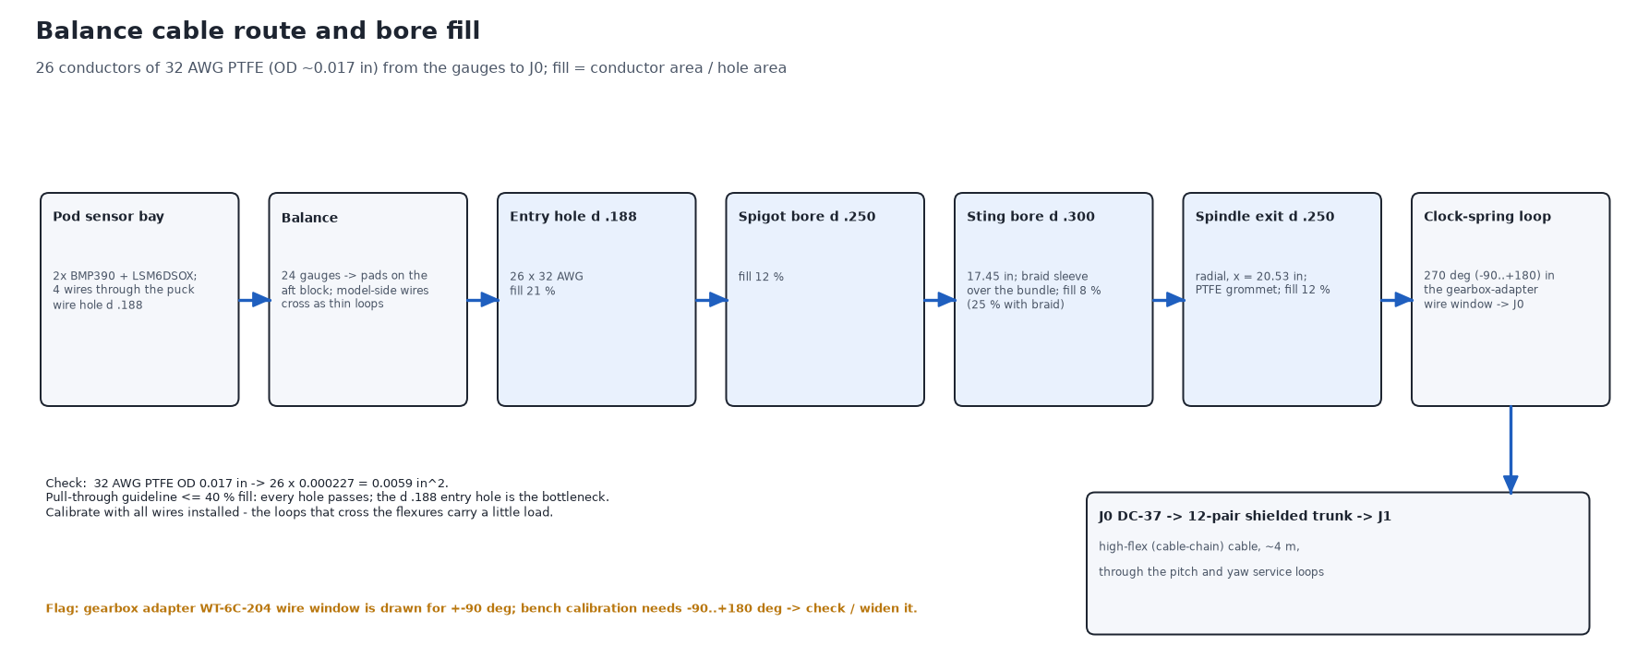
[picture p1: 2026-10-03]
assets/electronics/harness_route.png

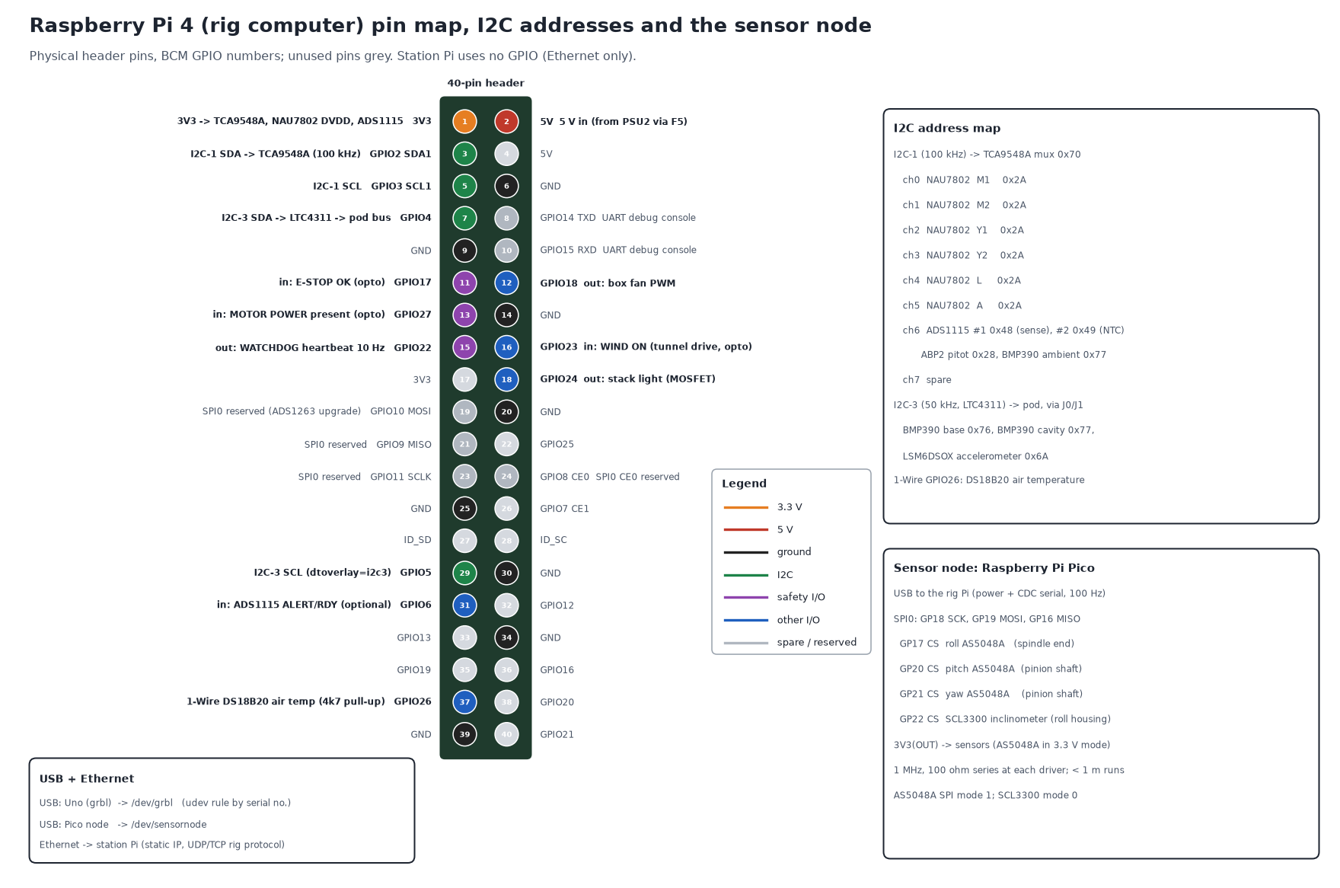
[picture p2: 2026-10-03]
assets/electronics/pinmap.png

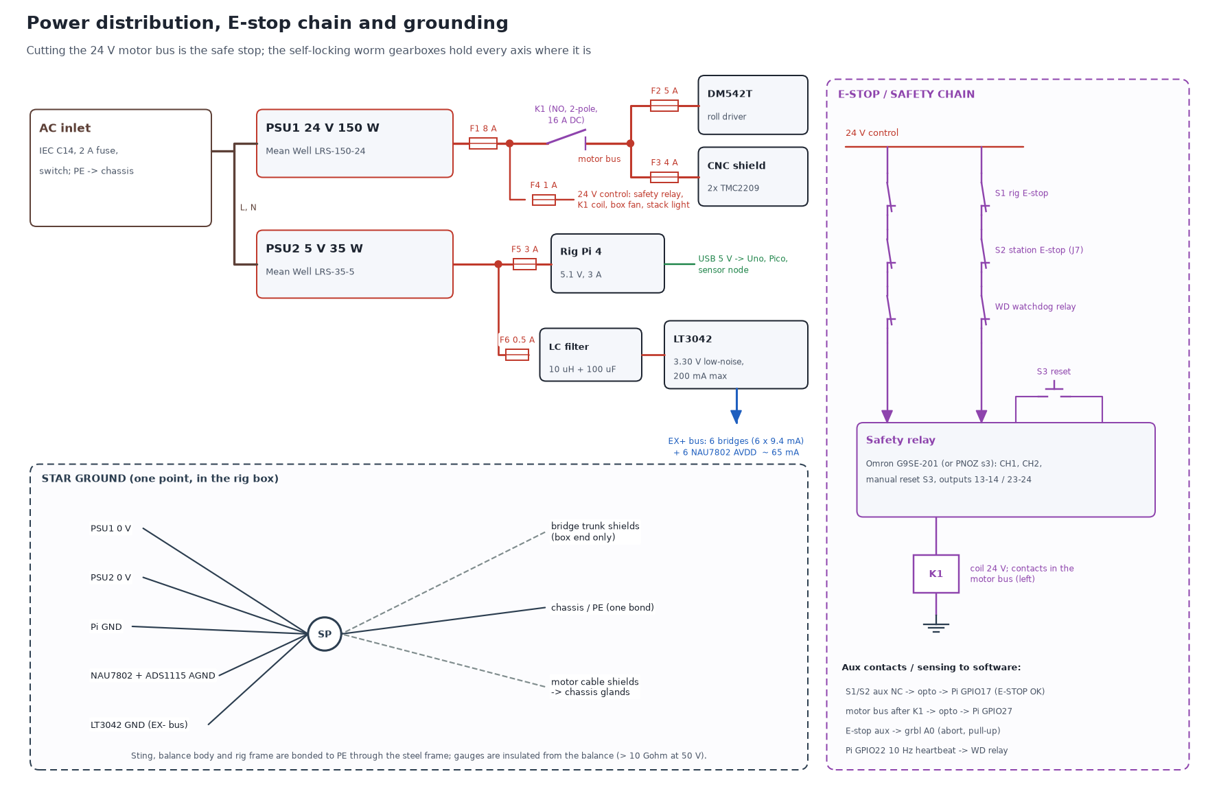
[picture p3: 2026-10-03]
assets/electronics/power_safety.png

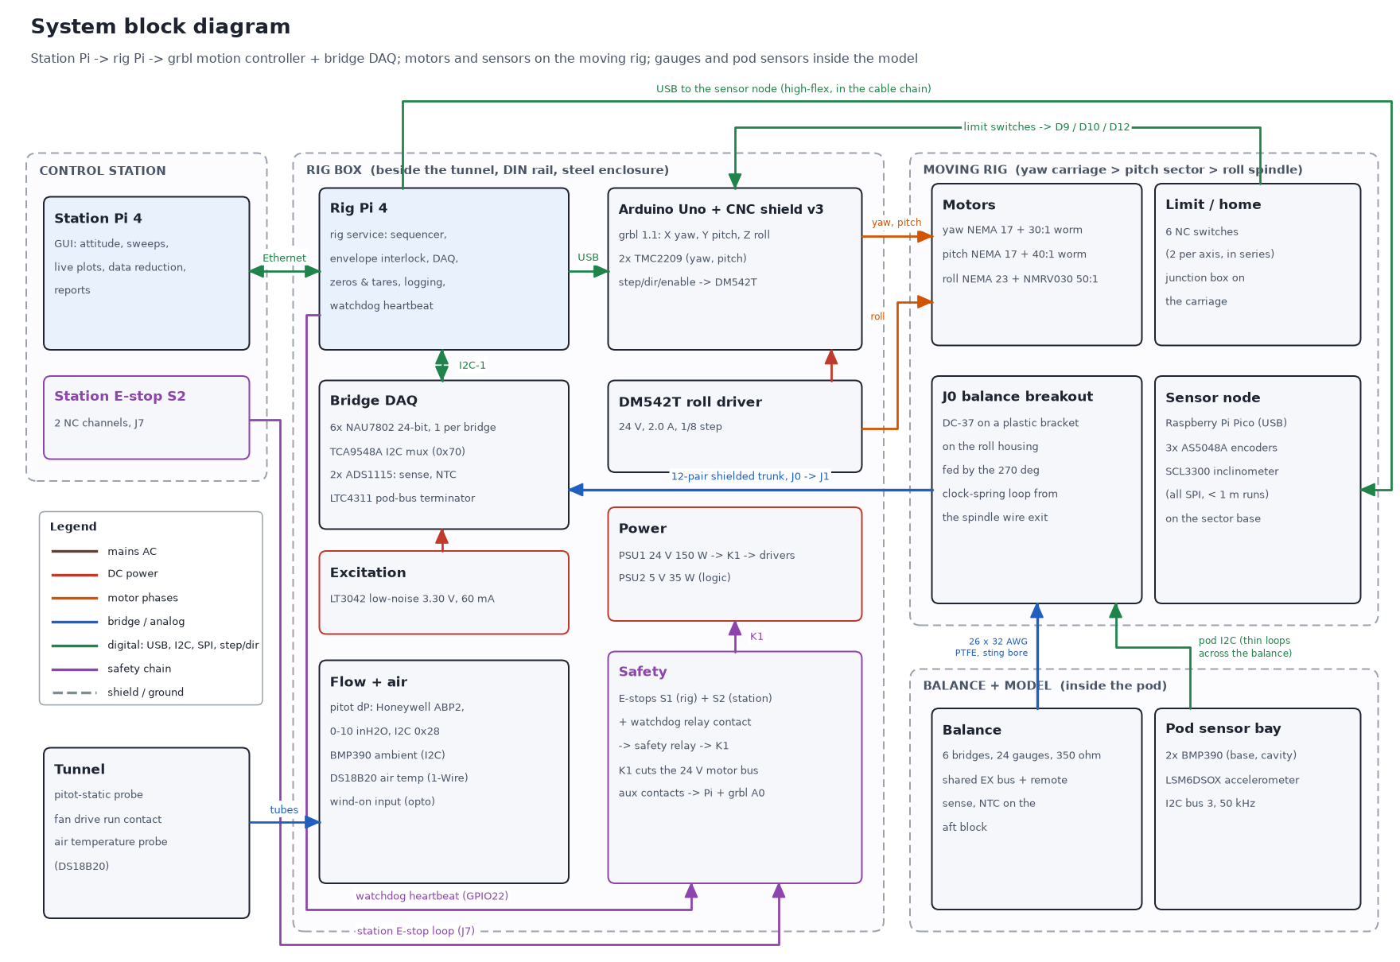
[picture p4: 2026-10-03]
assets/electronics/block.png

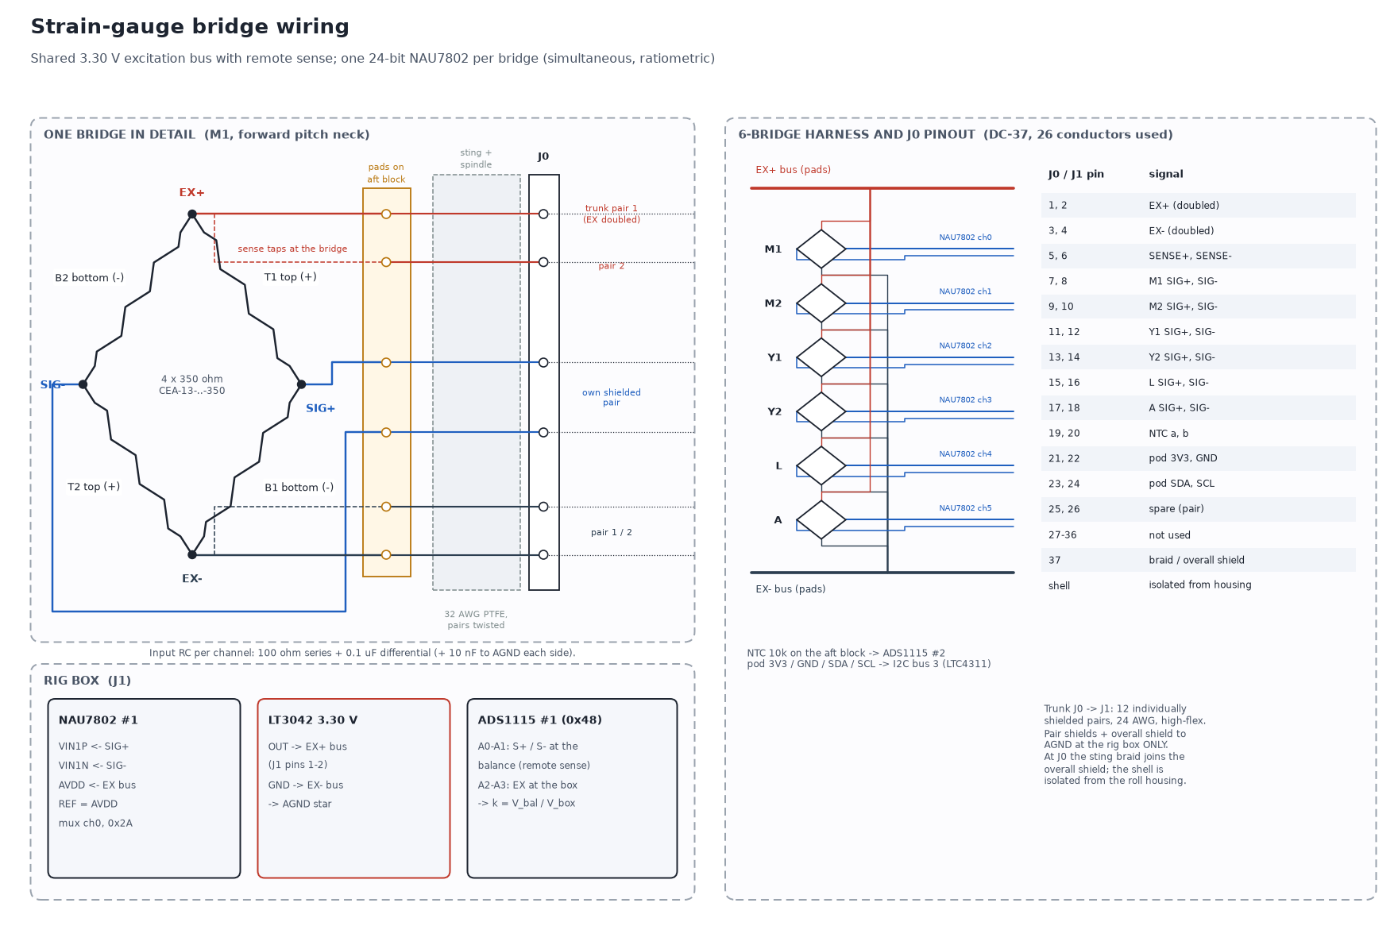
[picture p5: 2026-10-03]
assets/electronics/bridge.png

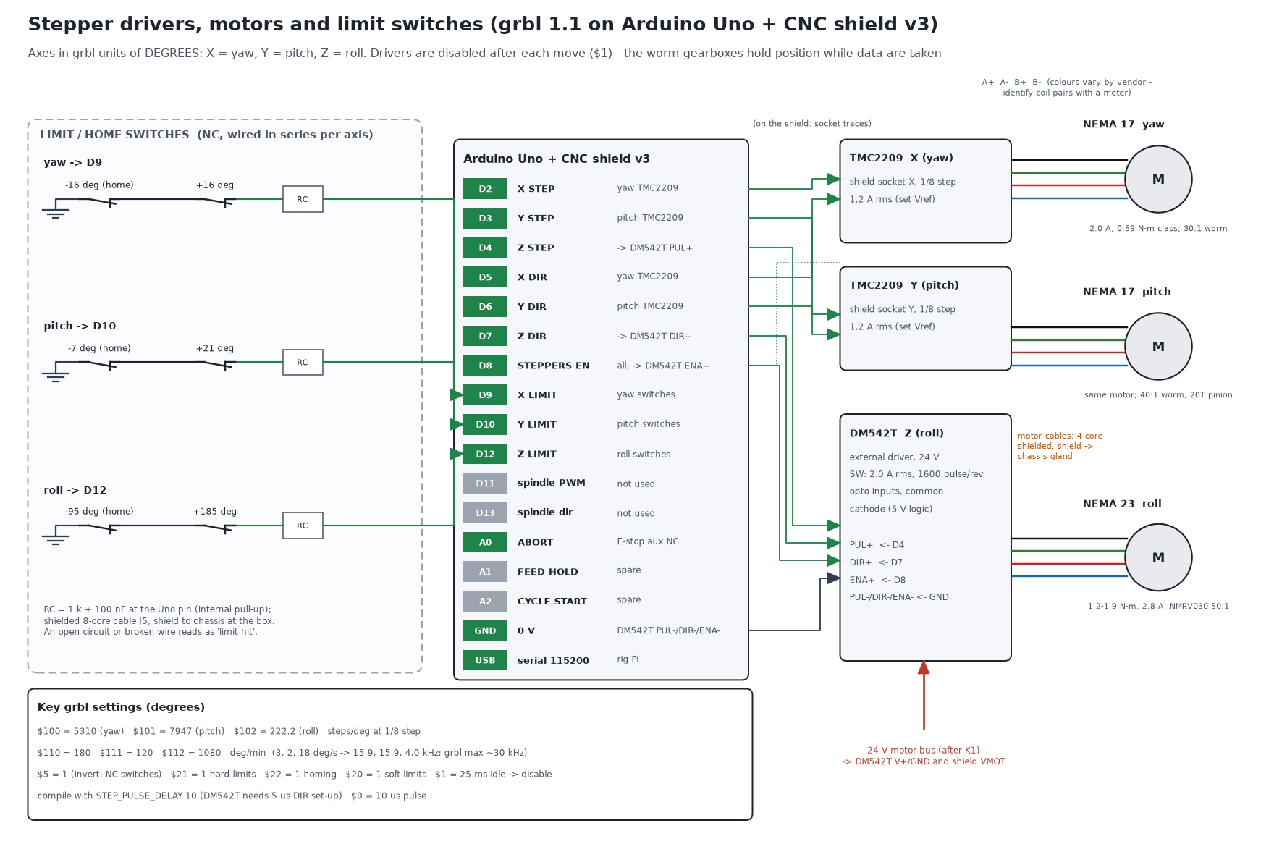
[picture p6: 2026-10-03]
assets/electronics/steppers.png

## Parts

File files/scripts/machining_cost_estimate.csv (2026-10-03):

dwg | name | qty | material | tol | envelope_in | part_lb | stock_lb | ship_kg | hours | CN | CN_landed | SCS | US | SHOP | scs_ok | note
WT-6C-001 | Balance, 6-component | 1 | 7075-T651 | ultra | 0.75 x 1.25 x 6.35 | 0.31 | 0.8 | 0.24 | 16.1 | 194-386 | 369-733 |  | 1569-2432 | 1145-1796 | False | wire EDM necks/flexures (rough + 2 skims), +-.0005 sections, CMM report; the cost driver
WT-6C-002 | Puck, model interface | 1 | 6061-T6 | prec | 0.40 x 1.70 x 1.70 | 0.06 | 0.18 | 0.11 | 2.9 | 26-58 | 49-110 |  | 279-444 | 192-313 | False | dowel holes +.0005; flatness .0005 is beyond SendCutSend
WT-6C-003 | Sting | 1 | 4140 PH | ultra | 0.88 x 0.88 x 17.45 | 2.42 | 5.03 | 1.37 | 9.6 | 167-320 | 301-576 |  | 957-1498 | 705-1119 | False | 0.300 bore x 17 in = gun drilling (or start from DOM/honed tube); OD ground, straightness .002
WT-6C-201 | Spindle, roll | 1 | 4140 PH | ultra | 1.50 x 1.50 x 6.97 | 1.51 | 5.42 | 0.86 | 11.0 | 144-284 | 259-511 |  | 1082-1702 | 781-1250 | False | 35 k5 seats ground; D-D bore by wire EDM; M35x1.5 thread; keyway
WT-6C-202 | Housing, roll spindle | 1 | 6061-T6 | prec | 2.90 x 2.90 x 3.47 | 1.89 | 3.32 | 1.07 | 6.1 | 57-119 | 108-226 |  | 618-986 | 428-699 | False | 55 H7 bores line-bored in one setup (runout .0005)
WT-6C-203-1 | Cap, front | 1 | 6061-T6 | prec | 0.24 x 2.90 x 2.90 | 0.14 | 0.24 | 0.18 | 2.5 | 24-54 | 46-103 |  | 238-380 | 164-267 | False
WT-6C-203-2 | Cap, rear | 1 | 6061-T6 | prec | 0.24 x 2.90 x 2.90 | 0.1 | 0.24 | 0.18 | 2.2 | 23-53 | 44-101 |  | 214-343 | 148-242 | False
WT-6C-204 | Adapter, gearbox | 1 | 6061-T6 | std | 0.55 x 2.90 x 2.90 | 0.17 | 0.6 | 0.2 | 1.9 | 19-45 | 36-86 | 66-124 | 193-311 | 133-219 | True
WT-6C-205 | Bracket, roll encoder | 1 | 6061-T6 | std | 0.12 x 1.50 x 1.50 | 0.02 | 0.04 | 0.09 | 1.2 | 12-32 | 23-61 | 40-80 | 121-197 | 83-137 | True
WT-6C-301 | Sleeve, calibration | 1 | 6061-T6 | prec | 1.85 x 1.85 x 5.60 | 0.76 | 2.22 | 0.43 | 6.5 | 61-128 | 116-243 |  | 646-1029 | 446-726 | False | 20 reamed load holes (pos .001) + 20 corner grooves
WT-6C-302 | Arm, roll calibration | 1 | 6061-T6 | std | 0.50 x 2.45 x 9.20 | 0.81 | 1.24 | 0.46 | 2.0 | 22-50 | 42-95 | 73-137 | 204-329 | 142-233 | True
WT-6C-303 | Stirrup, 45 deg | 1 | 6061-T6 | std | 0.30 x 3.24 x 3.57 | 0.09 | 0.49 | 0.22 | 1.8 | 18-43 | 34-82 | 60-115 | 182-294 | 126-207 | True
WT-6C-304 | Yoke, calibration | 1 | 6061-T6 | std | 1.40 x 1.97 x 2.41 | 0.13 | 0.83 | 0.2 | 2.3 | 24-54 | 46-103 | 81-151 | 228-366 | 157-258 | True
WT-6C-305 | Plate, head, cal. stand | 2 | 6061-T6 | std | 0.50 x 3.85 x 16.15 | 2.23 | 3.28 | 2.53 | 2.2 | 48-103 | 91-196 |  | 277-459 | 201-338 | False | 16.15 in long: over the SendCutSend 12 in limit
WT-6C-306-1 | Bridge, jack | 1 | 6061-T6 | std | 0.50 x 1.10 x 3.00 | 0.14 | 0.24 | 0.13 | 1.5 | 16-40 | 30-76 | 55-106 | 147-238 | 101-167 | True
WT-6C-306-2 | Spacer, cross | 2 | 6061-T6 | std | 0.80 x 0.80 x 3.00 | 0.18 | 0.27 | 0.26 | 1.6 | 23-60 | 44-114 | 70-141 | 161-267 | 112-188 | True
WT-6C-307 | Tube, base, cal. stand | 1 | 6061-T6 | std | 1.50 x 3.00 x 31.00 | 3.2 | 3.4 | 1.89 | 1.9 | 27-51 | 51-97 |  | 212-340 | 151-247 | False | cut + drill purchased 3x1.5x.125 tube (31 in)
WT-6C-308/309/310 | Uprights (4), axles (2), pulleys (3) | 1 | 6061-T6 | std | 0.00 x 0.00 x 0.00 | 0.0 | 2.4 | 0.82 | 5.8 | 58-121 | 110-230 | 210-377 | 572-913 | 396-645 | True | pulley uprights, axles (5/16 ground rod) and 2 in pulleys with R5-2Z bearings
WT-6C-401 | Cheek, pitch sector | 2 | 6061-T6 | prec | 0.50 x 7.10 x 14.75 | 2.59 | 5.38 | 2.93 | 4.5 | 79-163 | 150-310 |  | 530-865 | 382-634 | False | arc track slots profile .002; machine both stacked
WT-6C-402 | Rack plate, pitch | 1 | 6061-T6 | prec | 0.50 x 3.29 x 13.94 | 0.89 | 2.45 | 0.69 | 6.0 | 86-176 | 163-334 |  | 607-949 | 449-708 | False | ~87 internal teeth m1.25 by wire EDM
WT-6C-403 | Plate, base, pitch | 1 | 6061-T6 | std | 0.75 x 5.70 x 9.20 | 2.42 | 4.11 | 1.37 | 2.1 | 34-71 | 65-135 |  | 243-396 | 173-288 | False | 0.75 in plate, 9.2 x 5.7 in; flat .002 is tighter than SCS
WT-6C-404-1 | Tie, top | 1 | 6061-T6 | std | 1.38 x 2.53 x 3.00 | 0.55 | 1.26 | 0.31 | 1.6 | 21-47 | 40-89 | 65-123 | 167-272 | 117-194 | True
WT-6C-404-2/3 | Spacers, pitch | 2 | 6061-T6 | std | 0.90 x 1.00 x 3.00 | 0.25 | 0.37 | 0.29 | 1.5 | 23-60 | 44-114 | 69-141 | 159-263 | 110-185 | True
WT-6C-405 | Bracket, pitch drive | 1 | 6061-T6 | prec | 1.30 x 1.88 x 2.30 | 0.2 | 0.71 | 0.18 | 2.2 | 23-52 | 44-99 |  | 223-359 | 154-253 | False | 22 H7 bearing bore
WT-6C-406 | Pinion shaft (gear bought) | 1 | 4140 PH | prec | 0.00 x 0.00 x 0.00 | 0.0 | 0.3 | 0.2 | 3.0 | 33-64 | 59-115 |  | 283-443 | 198-317 | False | 8 h6 ground shaft + rebore/pin the stock m1.25 20T gear
WT-6C-501 | Rail, yaw, inner | 1 | 6061-T6 | prec | 0.50 x 3.45 x 15.61 | 1.07 | 2.86 | 0.79 | 4.6 | 49-102 | 93-194 |  | 471-754 | 327-535 | False | V-edges on both arcs (hard anodize preferred)
WT-6C-502 | Rail, yaw, outer | 1 | 6061-T6 | prec | 0.50 x 5.27 x 24.99 | 1.8 | 6.79 | 1.61 | 5.3 | 69-139 | 131-264 |  | 568-913 | 400-657 | False
WT-6C-503 | Rack, yaw, floor | 1 | 6061-T6 | prec | 0.50 x 5.77 x 10.67 | 0.45 | 3.2 | 0.81 | 6.1 | 89-183 | 169-348 |  | 624-977 | 462-729 | False | ~80 external teeth m1.25 by wire EDM
WT-6C-504 | Plate, yaw carriage | 1 | 6061-T6 | std | 0.50 x 12.36 x 18.69 | 7.27 | 11.64 | 4.12 | 2.9 | 65-127 | 124-241 |  | 389-638 | 286-478 | False | ~11 x 18 in sector plate
WT-6C-505 | Pinion mods, yaw (gear bought) | 1 | steel | prec | 0.00 x 0.00 x 0.00 | 0.0 | 0.0 | 0.2 | 1.7 | 15-29 | 27-52 |  | 157-246 | 109-175 | False | rebore + keyway/set screw on a stock m1.25 20T gear
WT-6C-506 | Spacers, wheel (plain + eccentric) | 8 | 6061-T6 | std | 0.00 x 0.00 x 0.00 | 0.0 | 0.04 | 1.6 | 3.3 | 64-183 | 122-348 | 174-380 | 336-572 | 235-403 | True

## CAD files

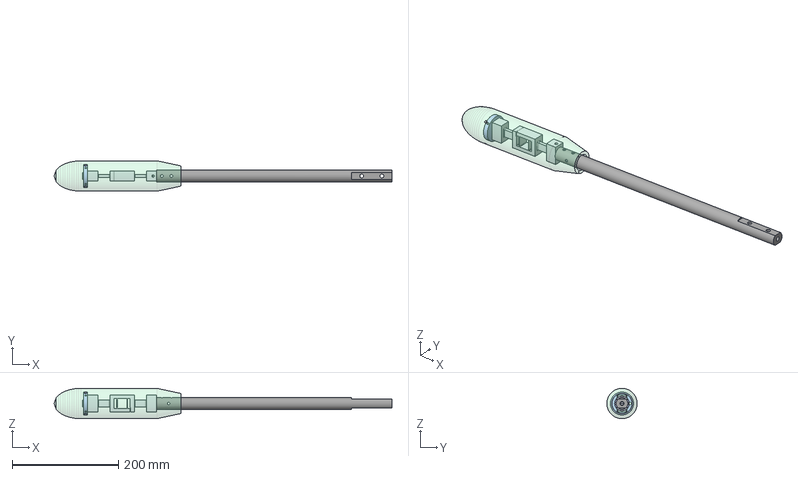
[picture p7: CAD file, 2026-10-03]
files/cad/six_component_balance/assembly_6c_flight.step
636.3 x 57.1 x 57.1 mm
balance_6c_7075
model_puck_6061
sting_4140
pod_reference_2.25in_printed

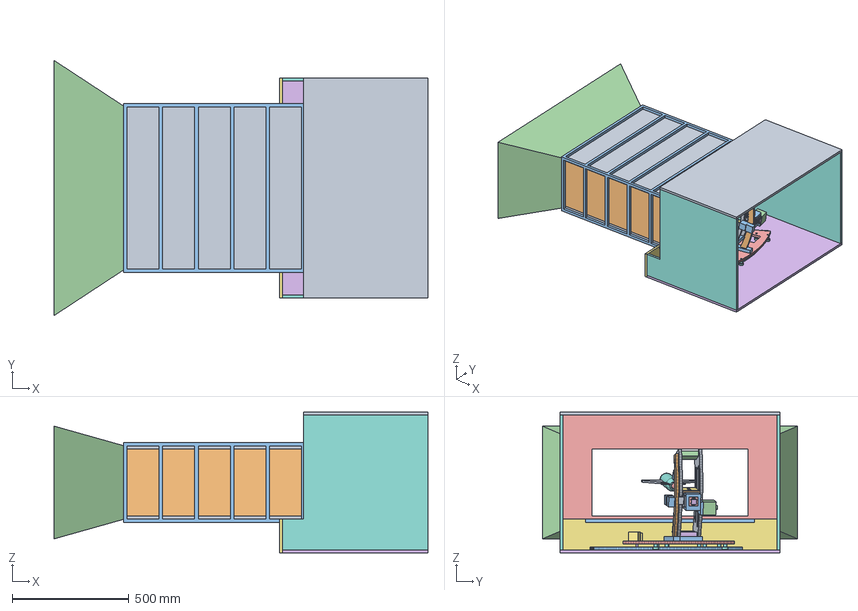
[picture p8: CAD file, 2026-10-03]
files/cad/system_assembly/assembly_system_in_tunnel.step
1600.2 x 1092.2 x 602.0 mm

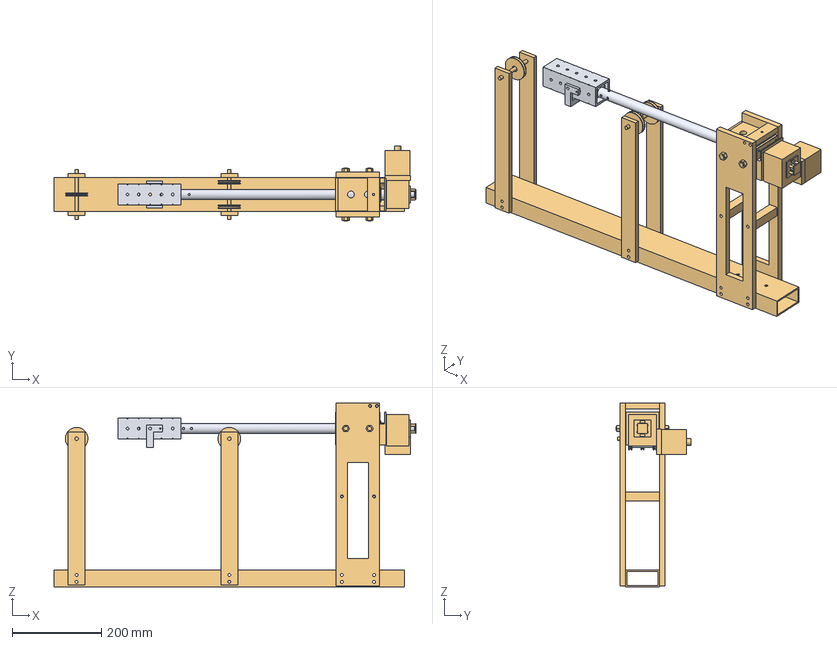
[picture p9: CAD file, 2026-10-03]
files/cad/calibration_6c/assembly_calibration_6c_roll90.step
812.9 x 168.9 x 412.8 mm
spindle
sting
balance
sleeve_6c
yoke_6c
roll_housing_6061
roll_front_cap_6061
roll_rear_cap_6061
roll_gearbox_adapter_6061
roll_gearbox_NMRV030_envelope
roll_motor_NEMA23_envelope
roll_encoder_bracket
roll_encoder_board_AS5048A_envelope
head_plate_p
head_plate_m
jack_bridge_v2
base_tube_v2
cross_spacer0
cross_spacer1
stud0
stud1
stud2
stud3
drag_upright_p
drag_upright_m
drag_axle
thrust_upright_p
thrust_upright_m
thrust_axle
thrust_pulley
drag_pulley_p
drag_pulley_m

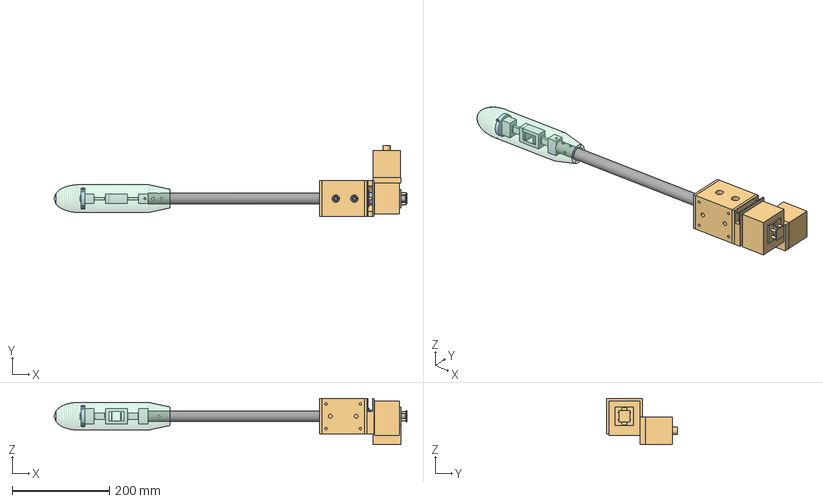
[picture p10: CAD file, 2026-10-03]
files/cad/roll_spindle/assembly_roll_spindle_phi+0.step
725.3 x 146.1 x 95.3 mm
spindle_4140
sting
balance
puck
pod
housing_6061
front_cap_6061
rear_cap_6061
gearbox_adapter_6061
gearbox_NMRV030_envelope
motor_NEMA23_envelope
encoder_bracket
encoder_board_AS5048A_envelope
bearing_or_nut_0
bearing_or_nut_1
bearing_or_nut_2

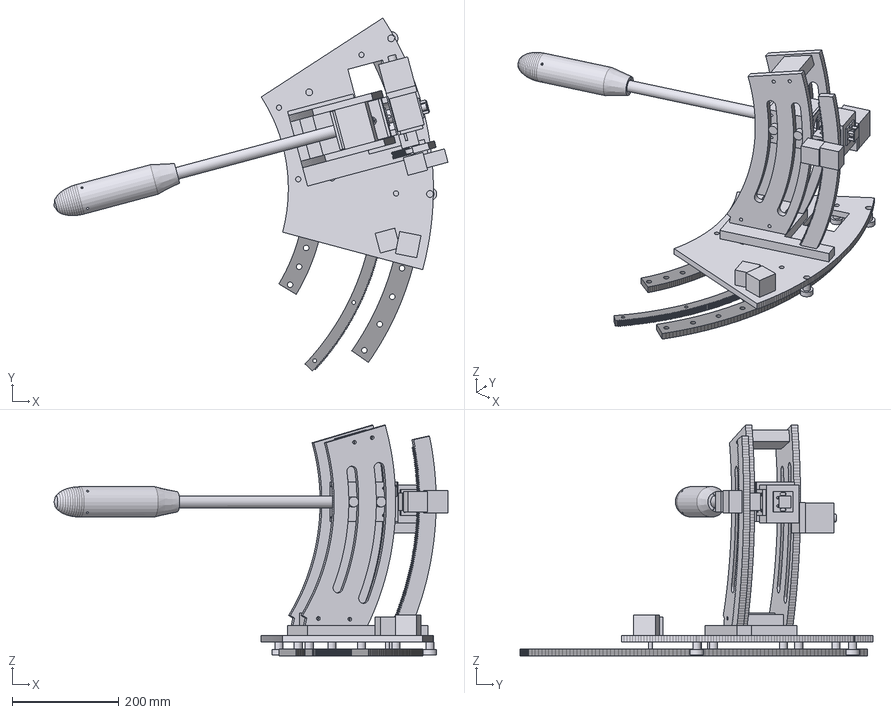
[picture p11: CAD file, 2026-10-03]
files/cad/yaw_carriage/assembly_yaw_carriage_psi+15.step
738.0 x 661.2 x 431.8 mm
carriage_plate
pinion
yaw_gearmotor
wheel0
wheel1
wheel2
wheel3
wheel4
wheel5
wheel6
wheel7
sector_cheek_plus_y
sector_cheek_minus_y
sector_rack_plate
sector_base_plate
sector_top_tie
sector_spacer0
sector_spacer1
pitch_spindle
pitch_sting
pitch_balance
pitch_puck
pitch_pod
pitch_housing_6061
pitch_front_cap_6061
pitch_rear_cap_6061
pitch_gearbox_adapter_6061
pitch_gearbox_NMRV030_envelope
pitch_motor_NEMA23_envelope
pitch_encoder_bracket
pitch_encoder_board_AS5048A_envelope
pitch_follower0
pitch_follower1
pitch_follower2
pitch_follower3
pitch_drive_bracket
pitch_pinion
pitch_pitch_gearmotor
rail_inner
rail_outer
floor_rack

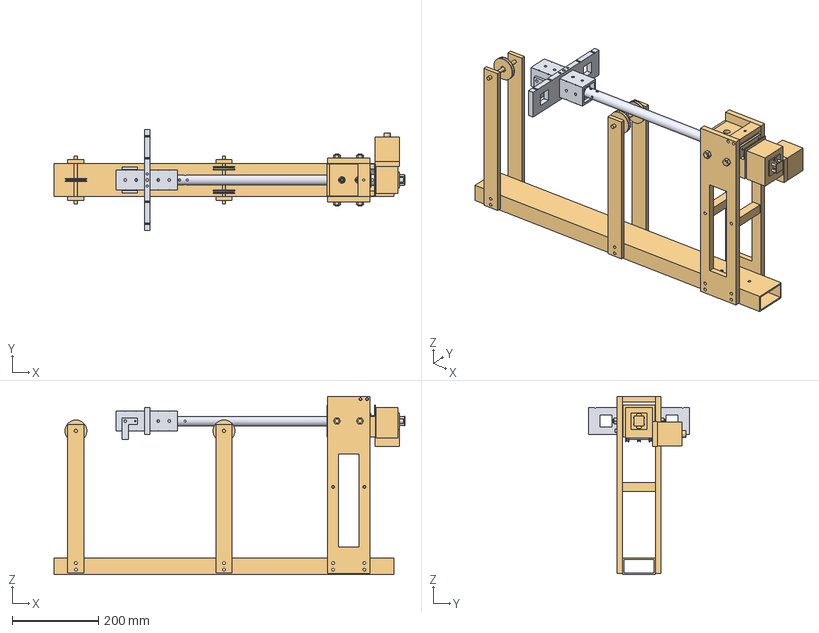
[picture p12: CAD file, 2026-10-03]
files/cad/calibration_6c/assembly_calibration_6c_roll0.step
812.9 x 233.7 x 412.8 mm
spindle
sting
balance
sleeve_6c
roll_arm
yoke_6c
roll_housing_6061
roll_front_cap_6061
roll_rear_cap_6061
roll_gearbox_adapter_6061
roll_gearbox_NMRV030_envelope
roll_motor_NEMA23_envelope
roll_encoder_bracket
roll_encoder_board_AS5048A_envelope
head_plate_p
head_plate_m
jack_bridge_v2
base_tube_v2
cross_spacer0
cross_spacer1
stud0
stud1
stud2
stud3
drag_upright_p
drag_upright_m
drag_axle
thrust_upright_p
thrust_upright_m
thrust_axle
thrust_pulley
drag_pulley_p
drag_pulley_m

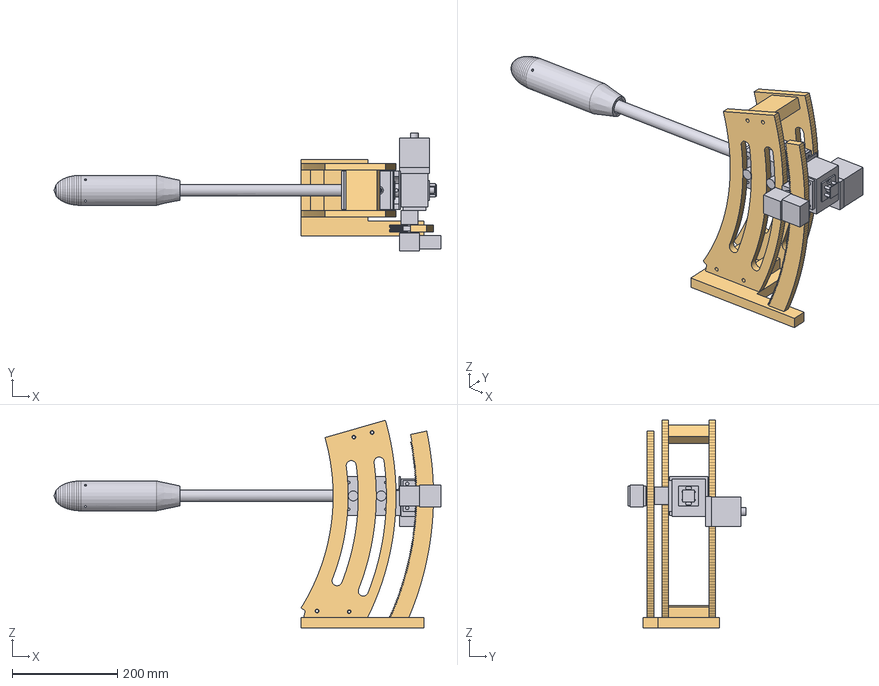
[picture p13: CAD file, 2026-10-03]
files/cad/pitch_sector_motorized/assembly_pitch_sector_alpha+0.step
734.3 x 224.8 x 393.7 mm
m_spindle
m_sting
m_balance
m_puck
m_pod
m_housing_6061
m_front_cap_6061
m_rear_cap_6061
m_gearbox_adapter_6061
m_gearbox_NMRV030_envelope
m_motor_NEMA23_envelope
m_encoder_bracket
m_encoder_board_AS5048A_envelope
m_follower0
m_follower1
m_follower2
m_follower3
m_drive_bracket
m_pinion
m_pitch_gearmotor
f_cheek_plus_y
f_cheek_minus_y
f_rack_plate
f_base_plate
f_top_tie
f_spacer0
f_spacer1

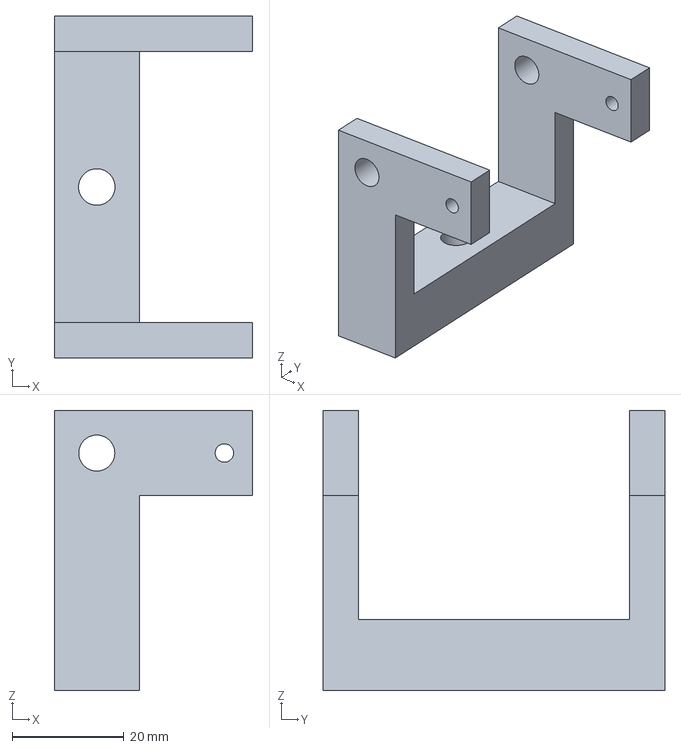
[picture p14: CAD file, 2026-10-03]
files/cad/calibration_6c/yoke_6c_6061.step
35.6 x 61.2 x 50.2 mm

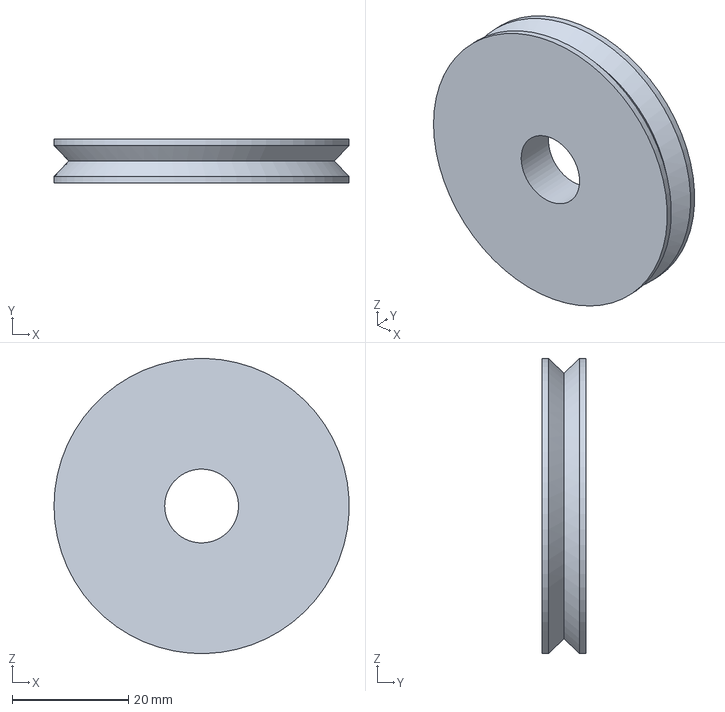
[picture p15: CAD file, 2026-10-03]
files/cad/calibration_stand/pulley_2in.step
50.8 x 7.62 x 50.8 mm

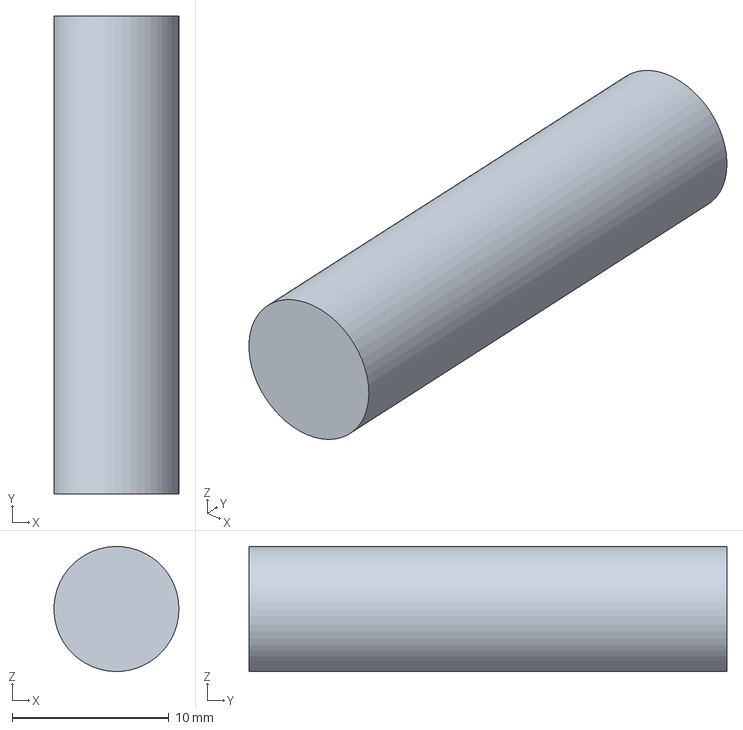
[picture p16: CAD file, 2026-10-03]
files/cad/pitch_sector_motorized/pinion_shaft_8mm.step
7.97 x 30.5 x 7.97 mm

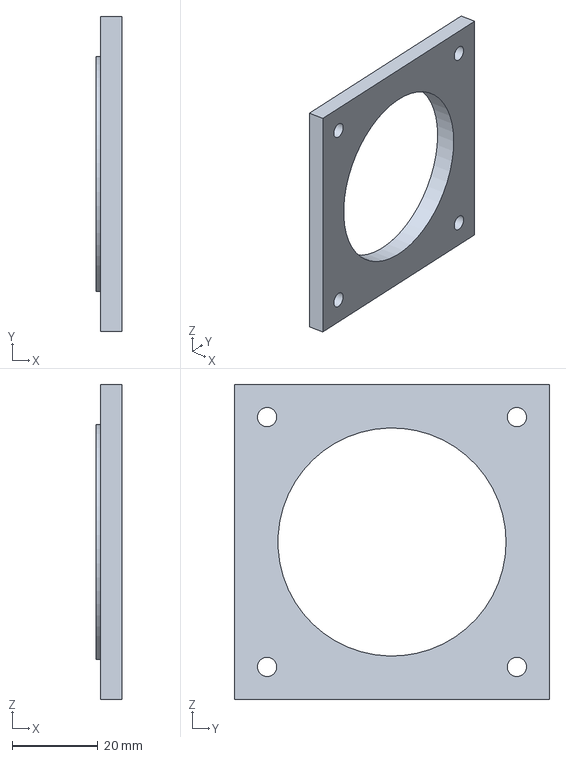
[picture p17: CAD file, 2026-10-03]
files/cad/roll_spindle/rear_cap_6061.step
6.10 x 73.7 x 73.7 mm

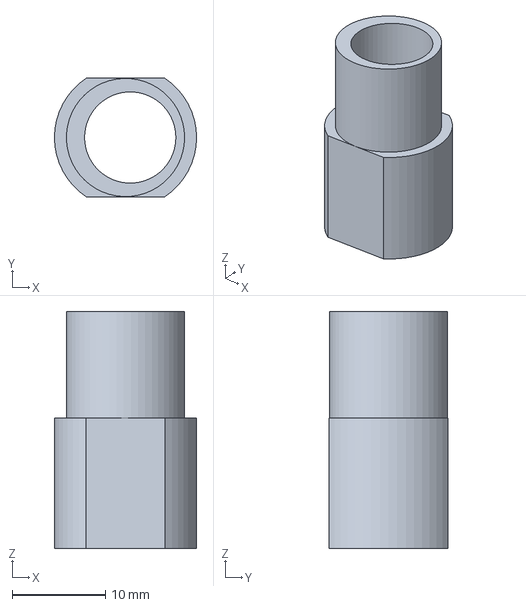
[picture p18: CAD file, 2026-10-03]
files/cad/yaw_carriage/wheel_spacer_eccentric.step
15.2 x 12.7 x 25.4 mm

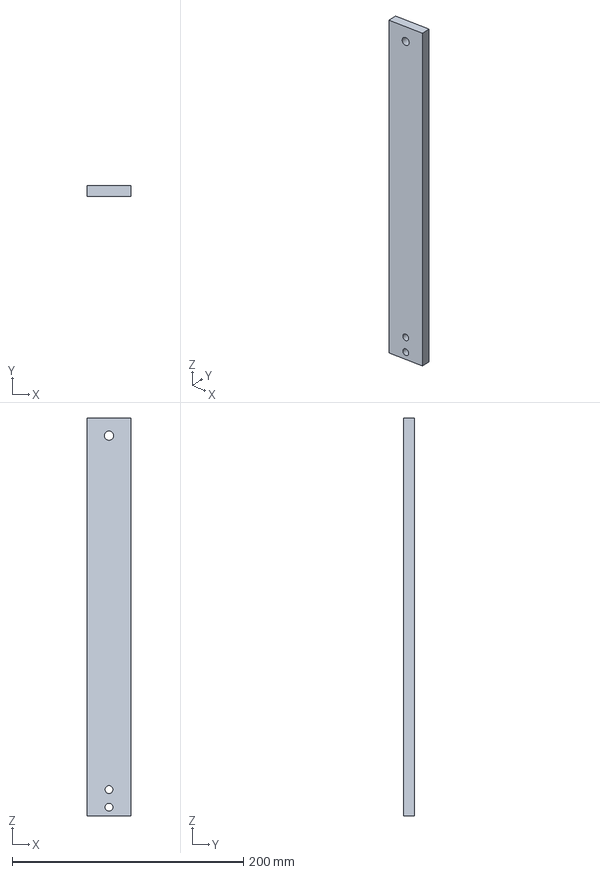
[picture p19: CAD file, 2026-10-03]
files/cad/calibration_stand/drag_upright.step
38.1 x 9.52 x 344.2 mm

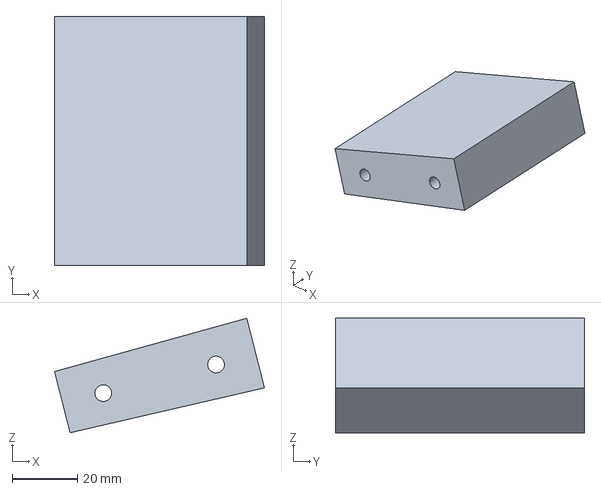
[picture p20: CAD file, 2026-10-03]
files/cad/pitch_sector_motorized/top_tie.step
64.1 x 76.2 x 35.0 mm

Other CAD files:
files/cad/roll_spindle/assembly_roll_spindle_phi+90.step
files/cad/calibration_6c/assembly_calibration_6c_roll45.step
files/cad/roll_spindle/housing_6061.step
files/cad/six_component_balance/sting_4140.step
files/cad/calibration_6c/base_tube_v2.step
files/cad/calibration_6c/cross_spacer_6061.step
files/cad/calibration_6c/head_plate_v2_6061.step
files/cad/calibration_6c/jack_bridge_v2_6061.step
files/cad/calibration_6c/roll_arm_6061.step
files/cad/calibration_6c/sleeve_6c_6061.step
files/cad/calibration_6c/stirrup_45_6061.step
files/cad/calibration_stand/thrust_axle.step
files/cad/calibration_stand_3comp_superseded/assembly_calibration_stand_aluminum.step
files/cad/calibration_stand_3comp_superseded/base_tube.step
files/cad/calibration_stand_3comp_superseded/foot_block.step
files/cad/calibration_stand_3comp_superseded/head_plate.step
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

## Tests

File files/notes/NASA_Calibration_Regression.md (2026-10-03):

# Notes: Ulbrich & Bader, "Analysis of Sting Balance Calibration Data Using Optimized Regression Models"

- File: `references/NASA_Sting_Balance_Calibration_Regression_2010.pdf` (29 pp.). Published as AIAA 2009-5372, 45th Joint Propulsion Conf., Denver, Aug 2009. Authors: N. Ulbrich (Jacobs/NASA Ames), J. Bader (NASA Ames).
- I read every page. Page images were checked for every equation, table and figure (pp. 5-16, 18-29).
- Page numbers below are the PDF page numbers, which match the printed folios.

---

## 1. Summary

- **What was calibrated (p. 4).** A Gulfstream sting balance with only two **moment gauges**, one forward and one aft of the balance moment center (BMC).
  - Gauge spacing d = 5.5 in (p. 15).
  - Total length about 28 in, with a 30 deg bend.
- **How it was loaded (p. 4, Fig. 4 p. 24).** Dead weights only. The balance was inverted to get positive normal force.
  - Four moment arms were used: 16.52, 18.52, 20.52 and 25.92 in, all on the same side of the BMC.
  - The load range was about ±20 lbf and ±410 in-lbf.
- **Key modelling choice (Table 1, p. 5).** The regressors are the BMC loads F (normal force) and M (pitching moment). The responses are the **difference R2 - R1**, which is nearly proportional to F, and the **sum R1 + R2**, which is nearly proportional to M. Each response is then dominated by one linear term (Fig. 5a/5b, p. 24).
- **Term selection (pp. 3-4, Fig. 1 p. 22).** NASA's BALFIT "candidate math model search" picked:
  - R2 - R1 = ε0 + ε1·F (intercept plus F only).
  - R1 + R2 = η0 + η1·M + η2·M² (intercept, M and M²).
  - The search started from a linear lower bound and stopped at a full quadratic upper bound (pp. 6-7).
- **Why the full quadratic is worse.** It fits slightly better: residual std 0.084% / 0.039% of the largest response, against 0.106% / 0.047% for the optimized models. But its VIFs run up to about 23,000, so it is **overfitted** and predicts poorly (Figs. 6, 7, pp. 25-26).
- **First-principles check (pp. 7-16).** Classical moment-balance load transformations give R2 - R1 = γ·d·F. Cantilever-beam deflection of the sting explains the M² term: under load the moment arm changes. Theory and fit agree:
  - ε1: 11.94 (theory) vs 12.21 (fit) µV/V per lbf.
  - η1: 4.342 (theory) vs 4.345 (fit) µV/V per in-lbf.
  - η2 has the opposite sign to the simple theory and is 4-6x smaller. The paper explains this by **re-levelling the calibration fixture after each load**, which removes most of the arm change and leaves a slightly shortened arm (Fig. 10, p. 28; p. 16).
- **Lesson.** Pick regressors and responses that match the physics of the balance. Then use a statistically disciplined term search (significance, VIF, PRESS) rather than defaulting to a full quadratic. Control and record fixture geometry (levelling, load-point height) during dead-weight calibration, because it creates "nonlinear" terms on its own.

---

## 2. The sting-balance concept: how gauge outputs relate to loads

### 2.1 Moment-type vs force-type balance (Appendix, pp. 18-21; Figs. 11-12, p. 29)

- A **force-type balance** has gauges that respond to a force at the gauge location (F1, F2).
- A **moment-type balance** has gauges that respond to the bending moment at the gauge location (M1, M2). It uses the "two-moment method", and that is exactly our design.

Coordinates run along the balance axis:
- c1 = forward gauge centre.
- c2 = aft gauge centre.
- μ = BMC.

**Force-type, general BMC location (Table I, p. 19):**

```
F  = F1 + F2                                        (A.8a)
M  = F1(μ - c1) - F2(c2 - μ)                        (A.8b)
F1 = F (c2-μ)/(c2-c1) + M/(c2-c1)                   (A.8c)
F2 = F (μ-c1)/(c2-c1) - M/(c2-c1)                   (A.8d)
```

**Moment-type, general BMC location (Table II, p. 20):**

```
F  = (M2 - M1)/(c2 - c1)                            (A.21a)
M  = M1 (c2-μ)/(c2-c1) + M2 (μ-c1)/(c2-c1)          (A.21b)
M1 = M - F(μ - c1)                                  (A.21c)
M2 = M + F(c2 - μ)                                  (A.21d)
```

**Simplified forms with the BMC midway, d = c2 - c1, μ = d/2 (Tables III/IV, p. 21):**

```
Force type:   F = F1+F2 ;  M = (F1-F2) d/2 ;  F1 = F/2 + M/d ;  F2 = F/2 - M/d
Moment type:  F = (M2-M1)/d ;  M = (M1+M2)/2 ;  M1 = M - F d/2 ;  M2 = M + F d/2   (A.24a-d)
```

Sign convention: +F is up, +M is nose-up as in Fig. 12. The aft gauge (nearer the sting support) sees the larger moment from a forward-applied F.

### 2.2 Gauge outputs (pp. 8-9)

Each bridge output is assumed proportional to the moment at its electrical centre:

```
R1 = γ1·M1 ,  R2 = γ2·M2                            (9a,b)
```

Fitted sensitivities:
- γ1 = 2.1643 µV/V per in-lbf, σ = 0.0046 (Eq. 10a).
- γ2 = 2.1774, σ = 0.0044 (Eq. 10b).
- Common value γ = 2.1709, σ = 0.0079 (Eq. 11b).

The two differ by about 0.6%.

With γ1 = γ2 = γ:

```
R2 - R1 = γ (M2 - M1) = γ·d·F          ->  ε1' = γ·d        (13a, 13b, 14a, 14b)
R1 + R2 = γ (M1 + M2) = 2γ·M           ->  η1' = 2γ          (15a-c, 58b)
```

The theoretical intercept is 0. The fitted intercept is non-zero because it absorbs systematic offsets in the gauge outputs (p. 9).

**My extension (not in the paper).** If γ1 ≠ γ2, the exact forms are:

```
R2 - R1 = (γ1+γ2)/2 · d·F + (γ2 - γ1)·M
R1 + R2 = (γ1+γ2)·M      + (γ2 - γ1)·d/2·F
```

So a sensitivity mismatch between the two bridges shows up as a small **M term in the difference** model and a small **F term in the sum** model. In the paper, F and M were nearly collinear: every load went on with a fixed, one-sided arm, so M ≈ F·l. With F and M that strongly correlated, the search could not separate these terms. The balance's two load components remain fully coupled through the arm.

### 2.3 Why the sum carries an M² term (pp. 9-14, Figs. 8-10, pp. 27-28)

The true arm is l = lo + Δl, where lo is the nominal arm and Δl is the change from elastic bending. Then M = F(lo + Δl), and with Mo = F·lo:

```
R1 + R2 = 2γ·Mo + 2γ·F·Δl                                       (21)
```

Geometry: the cranked sting has its load point at a vertical offset h below the balance axis, with crank angle φ (15-20 deg).

- Similar triangles give Δl = l1 + l2 with l1/δ1 = l2/δ2 = h/(lo/cosφ) (Eq. 23).
- The tip deflection from the force dominates the deflection from the end moment: δ1/δ2 ≈ (2/3)·lo/(s·sinφ), roughly 20-26 (Eq. 25a/b). Therefore l2 ≈ 0 (Eq. 26).
- This gives Δl = h·δ/(lo/cosφ) (Eq. 27).

Deflection by the area-moment method (Eq. 28): δ = ∫ M(x)·x / (E(x)I(x)) dx. With the mean-value theorem (Eq. 29) and M(x) = F cosφ·x (Eq. 32):

```
δ  = F·lo³ / (3·E(ξ)I(ξ)·cos²φ)                                 (33b)
Δl = (1/(E(ξ)I(ξ))) · (h/3) · (1/cosφ) · F·lo²                  (35)
```

E(ξ)I(ξ) is unknown. It is estimated from the measured free-end slope angle Θ, assuming dΘ/dx is constant: δ ≈ (lo/cosφ)·Θ/2 (Eq. 40).

```
1/(E I) ≈ 3Θ / (2·Mo·sqrt(h² + lo²))                             (44)
Θ ≈ (k1·Mo + k2·F)·π/180 ,  k1 = +0.00329615 deg/(in-lbf), k2 = -0.01702055 deg/lbf   (45a-c)
```

- Over the arm range, |k2/lo| = 0.00066-0.00103, so it is neglected relative to k1 (Eqs. 48-51): Θ ≈ k1·(π/180)·Mo.
- Using sinφ = h/sqrt(h² + lo²) (Eq. 54):

```
Δl ≈ (k1·π/360) · tanφ · F·lo²                                  (55)
R1 + R2 ≈ η1'·Mo + η2'·Mo² ,  η1' = 2γ ,  η2' = γ·k1·π/180 · tanφ(lo)     (58a-c)
```

So the **M² term is a geometric nonlinearity**: deflection changes the moment arm. It is not a gauge nonlinearity.

Comparison with the fit:
- Theory (p. 16): η2' = 3.4e-5 to 4.5e-5 (µV/V)/(in-lbf)², Eq. 63a.
- Fit: η2 = -7.3e-6, Eq. 63b.

The paper's explanation (Fig. 10, p. 28; Observations 1-3, p. 16):
- After each load the fixture was **re-levelled** with an AMS inclinometer.
- Re-levelling removes most of the arm growth.
- The remaining curvature of the sting (A'B'C is not straight) shortens the effective arm, so l' = lo - Δl' < lo.
- Hence the small negative coefficient.

---

## 3. Regression model forms and term selection

### 3.1 Models (pp. 5-6)

```
Traditional quadratic (1a): R2 - R1 = α0 + α1 F + α2 M + α3 F² + α4 M² + α5 F·M
Traditional quadratic (1b): R1 + R2 = β0 + β1 F + β2 M + β3 F² + β4 M² + β5 F·M
Search bounds (2a/2b, 3a/3b): lower = intercept + principal linear term; upper = full quadratic
Optimized Model 1 (2c):     R2 - R1 = ε0 + ε1 F
Optimized Model 2 (3c):     R1 + R2 = η0 + η1 M + η2 M²
```

The loads are the regressors and the gauge outputs are the responses. This is the "calibration" direction. In use, the fitted equations have to be inverted, usually by iteration, to get loads from outputs.

### 3.2 BALFIT candidate math-model search (pp. 3-4, Fig. 1 p. 22)

1. **Pick a function-class combination.** Here: intercept, linear, squares and cross products in the loads.
2. **Find the "permitted math model".** This is the largest non-singular model for the data set. Treat each term as a column vector and test them one at a time with SVD: keep a column only if it is linearly independent of the columns already kept. This takes n - 1 SVD tests, and testing low-order terms first is the clearest order.
3. **Search** from the lower bound (intercept + the principal load term for that gauge) towards the upper bound. The search minimizes the **standard deviation of the PRESS residuals** (leave-one-out prediction residuals), which is the measure of predictive capability. It is subject to two constraints:
   - **Primary constraint:** every term must be significant. The t-statistic p-value must be below a threshold; the paper uses the most conservative value, **0.0001**.
   - **Secondary constraint:** no near-linear dependencies. The **VIF** must be below a threshold; the paper uses **5**, and the literature's "liberal" limit is 10.
4. **Optional "hierarchy rule"** applied after the search: add any missing lower-order terms. It is no longer allowed during the search because that gave suboptimal results (p. 4).
5. Only 20 candidate models were tested for the difference response (p. 6).

### 3.3 Results tables (Figs. 6a/6b p. 25, 7a/7b p. 26)

| Model | Term: coefficient (std err), VIF | Residual std |
|---|---|---|
| R2-R1, quadratic (6a) | Int -0.1051; F +12.0427 (0.0196), VIF 107; M +0.0083, VIF 107; F² +0.0050 (p 0.71), VIF 6358; M² 5.6e-6 (p 0.86), VIF 5291; F·M -0.0004 (p 0.78), VIF 22934 | 0.2044 µV/V = 0.0836% of largest response (244.5 µV/V) |
| R1+R2, quadratic (6b) | Int +0.1407; F +0.3110, VIF 107; M +4.3289; F² +0.1096 (p 0.019); M² 0.0002 (p 0.12); F·M -0.0091 (p 0.045); same VIFs | 0.7026 µV/V = 0.0393% of 1785.7 µV/V |
| R2-R1, optimized (7a) | Int -0.1116 (0.0229); F +12.2069 (0.0024), t = 5174, VIF 1.0 | 0.2583 µV/V = 0.1056% |
| R1+R2, optimized (7b) | Int +0.2028 (0.0996); M +4.3446 (0.0004), t = 11128; M² -7.3372e-6 (1.77e-6), t = -4.15, VIF 1.0 | 0.8430 µV/V = 0.0472% |

- The plots also report the ratio of largest residual to standard deviation: 4.07 / 2.57 for the quadratic models and 2.91 / 2.07 for the optimized models.
- The VIF of about 107 between F and M is a property of the **load schedule**: every point lies on M = F·l with l between 16.5 and 25.9 in, all on one side (Fig. 4). That makes F and M about 99.5% correlated.

---

## 4. Load-schedule notes from the paper

- **Dead weights through a calibration fixture at four horizontal stations** (moment arms). Positive and negative loads were obtained by flipping the balance upside-down (pp. 4, 23).
- **An AMS inclinometer on the model plate** was used to **re-level the fixture after each load**, which restores the load direction and most of the arm (pp. 4, 16, Fig. 10).
- The applied loads are plotted in the F-M plane (Fig. 4, p. 24). Only four lines through the origin are covered, so the F and M terms are poorly decoupled. A better schedule would include pure-F (load at the BMC), pure-M (couple) and arms on both sides of the BMC.
- The nominal moment Mo = F·lo uses the unloaded geometry. Any elastic change of arm, or any vertical offset h between the load point and the balance axis, therefore turns into an apparent M² (or F·M) term.

## 5. Accuracy metrics used

- Residual standard deviation expressed as a **% of the largest response magnitude**: 0.04-0.11% here.
- **Ratio of the largest residual to the standard deviation**: about 2-3 for a good model, about 4 for the overfitted one.
- **PRESS residual standard deviation**, the search metric for predictive capability.
- **t-statistic and p-value** of each coefficient.
- **VIF**: below 5 (strict) or below 10 (liberal). Thousands means the model is unusable.
- Physical **sanity check of the coefficients against theory**: γ·d and 2γ. This was within 2.2% and 0.06%. The ε1 mismatch implies an effective gauge spacing of 5.62 in instead of 5.5 in, i.e. the electrical centres are not exactly at the drawing locations.

## 6. Figure and table index

| Item | Page | Content |
|---|---|---|
| Fig. 1 | 22 | Flowchart of the BALFIT search: function class -> SVD -> p-value -> VIF -> PRESS -> optional hierarchy |
| Fig. 2 | 22 | Sting balance schematic: model moment centre, forward gauge M1, BMC M, aft gauge M2 at ±d/2 |
| Fig. 3a-c | 23 | Photos: sting balance with gauge fairings, the forward/aft gauge necks, inverted dead-weight calibration with AMS |
| Table 1 | 5 | Regressor/response options: (M1,M2 -> R1,R2) or (F,M -> R2-R1, R1+R2) |
| Fig. 4 | 24 | Calibration load points in the F-M plane, four arm lines |
| Fig. 5a/5b | 24 | R2-R1 vs F and R1+R2 vs M; both nearly linear (±245 and ±1786 µV/V) |
| Fig. 6a/6b | 25 | Quadratic fits: coefficients, VIFs (red), residual plots |
| Fig. 7a/7b | 26 | Optimized fits: coefficients, VIF = 1, residual plots |
| Fig. 8 | 27 | Calibration loads on the cranked sting: h, φ, lo, τ, μ, d/2 |
| Fig. 9a/9b | 27-28 | Arm correction from force-induced and moment-induced deflection |
| Fig. 10 | 28 | Effect of re-levelling on the arm: l = lo+Δl before, l' = lo-Δl' after |
| Figs. 11-12 | 29 | Force and moment definitions for the appendix load transformations |
| Tables I-IV | 19-21 | Load transformation equation sets |

---

## 7. Calibration plan for OUR 3-component balance (N, A, m)

The design comes from `balance_sizing.py`:
- Two bending necks at s = d = 2.4 in, with the BMC midway.
- Full scale: N = 15 lbf, A = 2 lbf, m = 10 in-lbf.
- At full scale the neck moment is 28 in-lbf, giving about 1.03 mV/V.
- So γ ≈ 1034/28 ≈ **36.9 µV/V per in-lbf** per neck bridge, if the necks are identical.
- The axial bridge gives about 0.78 mV/V at 2 lbf.

### 7.1 Responses and expected coefficients

Wire and record three bridges: R1 (forward neck), R2 (aft neck) and RA (axial flexure). Use the paper's Option 2 (Table 1, p. 5):

| Response | Physics | Expected principal coefficient | FS signal |
|---|---|---|---|
| D = R2 - R1 | γ·d·N | ε1 ≈ 36.9 × 2.4 ≈ **88.6 µV/V per lbf** | ≈ 1330 µV/V at N = 15 |
| S = R1 + R2 | 2γ·m | η1 ≈ **73.9 µV/V per in-lbf** | ≈ 740 µV/V at m = 10 |
| RA | axial flexure | λ1 ≈ 390 µV/V per lbf | ≈ 780 µV/V at A = 2 |

- The sum channel reaches only about 55% of the difference channel at full scale. That follows from sizing the necks for m + N·d/2. It is acceptable, but m resolution in in-lbf is set by noise on S.
- Compare the fitted ε1 and η1 with γ·d and 2γ, as the paper does on p. 15. γ comes from regressing R1 on M1 and R2 on M2 separately (Eqs. 9-11). Agreement within a few % confirms the gauge electrical centres. ε1/γ gives the **effective** d, which you should use for the BMC location.

### 7.2 Recommended regression terms

Regress outputs on loads, with candidate terms drawn from the full quadratic in (N, A, m): 10 terms including the intercept.

- **D = R2 - R1**
  - Start from: d0 + d1·N.
  - Expected additions: d2·m from γ1 ≠ γ2 mismatch, which our decorrelated schedule will resolve; d3·A from axial-load sensitivity of imperfectly matched neck bridges.
  - Accept N² or N·m only if they pass the significance and VIF tests.
- **S = R1 + R2**
  - Start from: s0 + s1·m.
  - Expected additions: s2·N from mismatch or BMC not exactly midway; s3·m² or s3·N·m from fixture-geometry or deflection effects (Section 7.4); s4·A if present.
- **RA**
  - Start from: a0 + a1·A.
  - Expected additions: a2·N and a3·m, the strong candidates. The plate axial strain from N and m (20.8 lbf per plate at full scale, per the script) only partly cancels in the bridge; the script estimates about 0.2% of A FS per N FS with 2% gauge mismatch. Also consider a4·N² and a5·N·m, because pitch rotation tilts gravity into the axial direction (Section 7.4), and a6·A·N.
- **Selection procedure.** This is BALFIT-style and easy to do in Python with numpy/statsmodels.
  1. Build the full-quadratic design matrix and drop any linearly dependent columns (rank or SVD test, low-order terms first).
  2. Starting from the lower bound, try adding each candidate term. Keep the model that gives the lowest **PRESS std**, where e_PRESS,i = e_i/(1 - h_ii), subject to **p < 0.001** for every term (0.0001 is the paper's most conservative value) and **VIF < 5**.
  3. Stop when no addition reduces PRESS std.
  4. Expect 2-4 terms per response. **Do not** default to the full 10-term quadratic.
- **Inversion for test use.** Write R = c0 + C1·x + C2·g(x), where x = [N, A, m] and g holds the selected nonlinear terms. Solve iteratively: x_{k+1} = C1⁻¹ [R - c0 - C2·g(x_k)]. Start from x_0 = C1⁻¹(R - c0); this converges in 2-3 iterations for small nonlinear terms.
- **Alternative (Option 1).** Regress R1 on (M1, M2, A) and R2 on (M1, M2, A). This is equivalent and also gives γ1 and γ2 directly as a diagnostic.

### 7.3 Dead-weight load schedule (about 90 points + about 15 check points)

**General practice:**
- Mount the calibration body (dummy pod with load stations) on the balance with the sting clamped to a rigid stand.
- Record a zero before and after each series (return-to-zero tells you about drift and hysteresis).
- Load up and down within each series.
- Invert the balance 180 deg in roll for the opposite sign of N, as the paper does (p. 4).
- Use a pulley with a low-friction bearing for A and for the opposite signs.
- Include the weight of the calibration body and hangers in the applied loads. Alternatively, define the zero with them on and account for their moment explicitly.

**Load stations.** Put knife-edge or ball load points on the balance centreline height (h = 0), at x = -2, -1, 0 (BMC), +1 and +2 in from the BMC. Add a pure-couple fixture: a horizontal arm with equal, opposite weights or pulleys.

| Series | Loads | Points (approx.) | Purpose |
|---|---|---|---|
| 1. N at BMC | N = 0, ±3.75, ±7.5, ±11.25, ±15 lbf, up and down | 18 | pure N: ε1 and N-sensitivity of S and RA |
| 2. N at offset stations | x = ±1 in: N up to ±10 lbf (m ≤ 10); x = ±2 in: N up to ±5 lbf; 3 levels each | 24 | **decorrelates N and m** (the paper's weakness, VIF 107) |
| 3. Pure pitching couple | m = ±2.5, ±5, ±7.5, ±10 in-lbf | 8-10 | pure m: η1, m² term, m→D mismatch term |
| 4. Axial alone | A = 0, ±0.5, ±1.0, ±1.5, ±2.0 lbf, up and down | 16 | λ1, A→D and A→S interactions |
| 5. Combined A + N | N = 0, ±7.5, ±15 at the BMC × A = 0.5, 1, 2 | 12-15 | A·N, N→RA, gravity-tilt effect |
| 6. Combined A + m | m = ±5, ±10 × A = 1, 2 | 8 | A·m |
| 7. Check (validation) points | random combinations inside the envelope, not used in the fit | 10-15 | true prediction error |

- **Sizing.** About 90 fitting points against at most 10 candidate terms per response gives plenty of degrees of freedom. Check that the load points fill the N-m envelope (|N| ≤ 15, |m| ≤ 10), not just lines through the origin. Plot it like the paper's Fig. 4, and check that the VIF between the N and m columns is close to 1.
- **Side force, roll and yaw.** These are not measured, but apply a few points at the survival levels (Y = 1 lbf, l = 16 in-lbf, n = 3 in-lbf) to quantify their interaction on D, S and RA. If an interaction is significant, budget for it in the uncertainty or reduce it with gauge placement on the neck sides.

### 7.4 How to judge fit quality

- Residual std as a % of the largest response:
  - Target ≤ 0.1-0.25% FS for a DIY build.
  - The paper's professional balance reached 0.05-0.1%.
  - 0.05% of FS corresponds to about 0.66 µV/V on D and about 0.37 µV/V on S, roughly 2-3 µV at 5 V excitation. Amplifier noise and stability will likely set the floor.
- Ratio of largest residual to std of 3 or less, and no structure in the residuals plotted against each load: a curve means a missing term, scatter by series means hysteresis or fixture problems.
- PRESS std close to the fit std. If it is much larger, the model is overfitted.
- Every term passes p < 0.001 and VIF < 5.
- **Check-point errors** (Series 7) expressed in load units, as % of N, A and m full scale. This is the number to quote for balance accuracy.
- **Physics checks:**
  - ε1 ≈ γ·d.
  - η1 ≈ 2γ.
  - Mismatch terms consistent with γ2 - γ1 from Option 1.
  - Any N→RA coefficient of about the size the script predicts.
- Repeatability: return-to-zero shift and up/down hysteresis, each below the target residual.

### 7.5 Design implications from the paper

1. **Two-moment geometry.**
   - Put the BMC exactly midway between the **electrical centres** of the two neck bridges, so the simplified transforms (A.24) apply and D ∝ N, S ∝ m.
   - Make the necks and gauge placement as identical as possible (γ1 ≈ γ2). A 1% mismatch puts about 0.01·m into D, and about 0.01·N·d/2 into S.
   - The paper's balance achieved 0.6% mismatch.
2. **Gauge spacing.** ε1 = γ·d, so increasing d raises N sensitivity relative to m. Our d = 2.4 in already gives a larger D signal than S signal at full scale. If m resolution matters more (Cm ~ 0.1 gives only about 1.9 in-lbf of aerodynamic m), consider a neck section that puts more strain into the sum output, or accept that S runs at about 19% of its FS in normal testing.
3. **Calibration-fixture geometry is part of the math model.** Any vertical offset h between a load point and the balance axis, combined with the elastic rotation θ of the necks and sting, changes the arm by about h·θ.
   - The script gives model pitch rotation ≈ 0.18 deg (0.0032 rad) at full scale.
   - A 1 in offset would therefore shift the arm by 0.003 in. On a 1 in arm that is a 0.3% error in m, larger than the fit target.
   - So put load points at h = 0 (knife edges on the centreline), or measure the angle.
4. **Gravity tilt into the axial bridge.** The same rotation tilts dead-weight N loads into the axial direction: A_spurious ≈ N·θ ≈ 15 × (0.002-0.004) ≈ 0.03-0.06 lbf. That is about 1.5-3% of A FS, a significant error.
   - Mitigation: mount a small inclinometer or accelerometer on the calibration body, as the paper's AMS unit does. Either re-level after each load as in the paper (Fig. 10), or compute the applied N and A in balance axes from the measured angle.
   - Do not let the regression absorb this as N² or N·m terms. In the tunnel, aerodynamic loads rotate with the model, so the error is not the same.
   - Also make the sting and calibration stand stiff. The 1 in steel sting rotates 0.035 deg at 12 lbf, per the script.
5. **Keep intercepts in every model.** They absorb bridge offsets and fixture tares, as discussed on p. 9.
6. **Prefer a parsimonious model.** A 2-4 term model with VIF ≈ 1 will predict better at untested load combinations than a full quadratic. This matters because tunnel loads (N with m about c/4 lift times its offset from the BMC) won't land exactly on calibration points.

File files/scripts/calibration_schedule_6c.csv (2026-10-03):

point | type | roll_deg | theta_deg | hang | station_in | arm_y_in | W_hang_lb | W_drag_lb | W_thrust_lb | temp_C | M1 | M2 | Y1 | Y2 | L | X
1 | zero | 0 |  | none |  |  | 0.0 | 0.0 | 0.0
2 | zero | 0 |  | none |  |  | 0.0 | 0.0 | 0.0
3 | zero | 0 |  | none |  |  | 0.0 | 0.0 | 0.0
4 | fit | 0 |  | yoke | -2.0 |  | 1.81 | 0.0 | 0.0
5 | check | 0 |  | yoke | -2.0 |  | 3.62 | 0.0 | 0.0
6 | fit | 0 |  | yoke | -2.0 |  | 5.44 | 0.0 | 0.0
7 | fit | 0 |  | yoke | -2.0 |  | 7.25 | 0.0 | 0.0
8 | fit | 0 |  | yoke | -2.0 |  | 3.62 | 0.0 | 0.0
9 | fit | 0 |  | yoke | -1.0 |  | 3.62 | 0.0 | 0.0
10 | fit | 0 |  | yoke | -1.0 |  | 7.25 | 0.0 | 0.0
11 | fit | 0 |  | yoke | -1.0 |  | 10.88 | 0.0 | 0.0
12 | fit | 0 |  | yoke | -1.0 |  | 14.5 | 0.0 | 0.0
13 | fit | 0 |  | yoke | -1.0 |  | 7.25 | 0.0 | 0.0
14 | check | 0 |  | yoke | 0.0 |  | 6.0 | 0.0 | 0.0
15 | fit | 0 |  | yoke | 0.0 |  | 12.0 | 0.0 | 0.0
16 | fit | 0 |  | yoke | 0.0 |  | 18.0 | 0.0 | 0.0
17 | fit | 0 |  | yoke | 0.0 |  | 24.0 | 0.0 | 0.0
18 | fit | 0 |  | yoke | 0.0 |  | 12.0 | 0.0 | 0.0
19 | fit | 0 |  | yoke | 1.0 |  | 3.75 | 0.0 | 0.0
20 | fit | 0 |  | yoke | 1.0 |  | 7.5 | 0.0 | 0.0
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

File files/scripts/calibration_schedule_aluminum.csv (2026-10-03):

point | type | roll_deg | station_in | W_hang_lb | W_drag_lb | W_thrust_lb | theta_deg | temp_C | R_fwd_mVV | R_aft_mVV | R_ax_mVV
1 | zero | 0 |  | 0.0 | 0.0 | 0.0
2 | zero | 0 |  | 0.0 | 0.0 | 0.0
3 | zero | 0 |  | 0.0 | 0.0 | 0.0
4 | fit | 0 | -2 | 1.69 | 0.0 | 0.0
5 | fit | 0 | -2 | 3.38 | 0.0 | 0.0
6 | fit | 0 | -2 | 5.06 | 0.0 | 0.0
7 | fit | 0 | -2 | 6.75 | 0.0 | 0.0
8 | fit | 0 | -2 | 3.38 | 0.0 | 0.0
9 | fit | 0 | -1 | 3.56 | 0.0 | 0.0
10 | fit | 0 | -1 | 7.12 | 0.0 | 0.0
11 | fit | 0 | -1 | 10.69 | 0.0 | 0.0
12 | fit | 0 | -1 | 14.25 | 0.0 | 0.0
13 | fit | 0 | -1 | 7.12 | 0.0 | 0.0
14 | fit | 0 | 0 | 6.06 | 0.0 | 0.0
15 | fit | 0 | 0 | 12.12 | 0.0 | 0.0
16 | fit | 0 | 0 | 18.19 | 0.0 | 0.0
17 | fit | 0 | 0 | 24.25 | 0.0 | 0.0
18 | fit | 0 | 0 | 12.12 | 0.0 | 0.0
19 | fit | 0 | 1 | 3.56 | 0.0 | 0.0
20 | fit | 0 | 1 | 7.12 | 0.0 | 0.0
21 | fit | 0 | 1 | 10.69 | 0.0 | 0.0
22 | fit | 0 | 1 | 14.25 | 0.0 | 0.0
23 | fit | 0 | 1 | 7.12 | 0.0 | 0.0
24 | fit | 0 | 2 | 1.69 | 0.0 | 0.0
25 | fit | 0 | 2 | 3.38 | 0.0 | 0.0
26 | fit | 0 | 2 | 5.06 | 0.0 | 0.0
27 | fit | 0 | 2 | 6.75 | 0.0 | 0.0
28 | fit | 0 | 2 | 3.38 | 0.0 | 0.0
29 | fit | 0 | 0 | 0.0 | 1.0 | 0.0
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

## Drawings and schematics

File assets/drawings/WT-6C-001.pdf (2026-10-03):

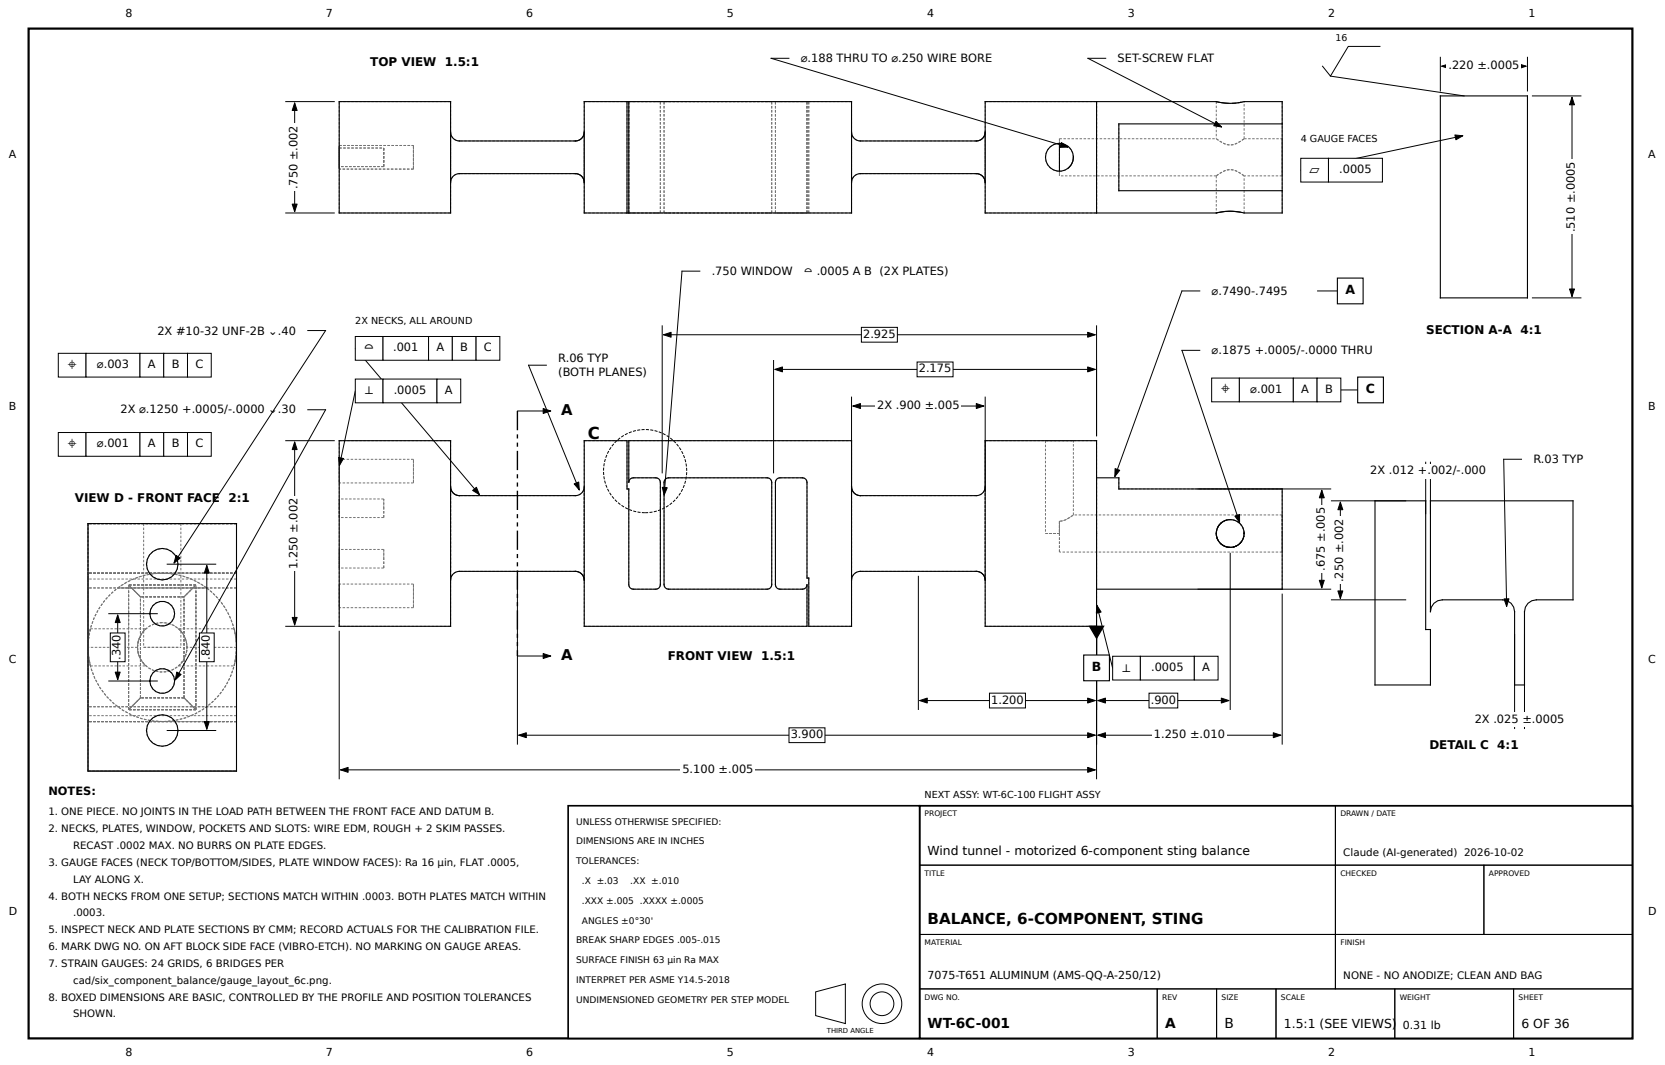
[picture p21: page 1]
FRONT VIEW 1.5:1; TOP VIEW 1.5:1; SECTION A-A 4:1; DETAIL C 4:1; PROJECT; DRAWN / DATE; TITLE; CHECKED; APPROVED; MATERIAL; FINISH; DWG NO. WT-6C-001; REV A; SIZE B; SCALE; 1.5:1 (SEE VIEWS); WEIGHT; SHEET; TOLERANCES:; .XXX ±.005 .XXXX ±.0005; ANGLES ±0°30'; THIRD ANGLE; ⌀.1875 +.0005/-.0000 THRU; R.06 TYP (BOTH PLANES); .750 WINDOW ⌓ .0005 A B (2X PLATES); ⌀.188 THRU TO ⌀.250 WIRE BORE; SET-SCREW FLAT; 2X #10-32 UNF-2B ⌄.40; 4 GAUGE FACES; R.03 TYP

2X NECKS, ALL AROUND

VIEW D - FRONT FACE 2:1

NOTES:
1. ONE PIECE. NO JOINTS IN THE LOAD PATH BETWEEN THE FRONT FACE AND DATUM B.
2. NECKS, PLATES, WINDOW, POCKETS AND SLOTS: WIRE EDM, ROUGH + 2 SKIM PASSES.
RECAST .0002 MAX. NO BURRS ON PLATE EDGES.
3. GAUGE FACES (NECK TOP/BOTTOM/SIDES, PLATE WINDOW FACES): Ra 16 µin, FLAT .0005,
LAY ALONG X.
4. BOTH NECKS FROM ONE SETUP; SECTIONS MATCH WITHIN .0003. BOTH PLATES MATCH WITHIN
5. INSPECT NECK AND PLATE SECTIONS BY CMM; RECORD ACTUALS FOR THE CALIBRATION FILE.
6. MARK DWG NO. ON AFT BLOCK SIDE FACE (VIBRO-ETCH). NO MARKING ON GAUGE AREAS.
7. STRAIN GAUGES: 24 GRIDS, 6 BRIDGES PER
cad/six_component_balance/gauge_layout_6c.png.
8. BOXED DIMENSIONS ARE BASIC, CONTROLLED BY THE PROFILE AND POSITION TOLERANCES
SHOWN.

NEXT ASSY: WT-6C-100 FLIGHT ASSY

UNLESS OTHERWISE SPECIFIED:

DIMENSIONS ARE IN INCHES

Wind tunnel - motorized 6-component sting balance

Claude (AI-generated) 2026-10-02

BALANCE, 6-COMPONENT, STING

BREAK SHARP EDGES .005-.015

SURFACE FINISH 63 µin Ra MAX

7075-T651 ALUMINUM (AMS-QQ-A-250/12)

NONE - NO ANODIZE; CLEAN AND BAG

INTERPRET PER ASME Y14.5-2018

UNDIMENSIONED GEOMETRY PER STEP MODEL

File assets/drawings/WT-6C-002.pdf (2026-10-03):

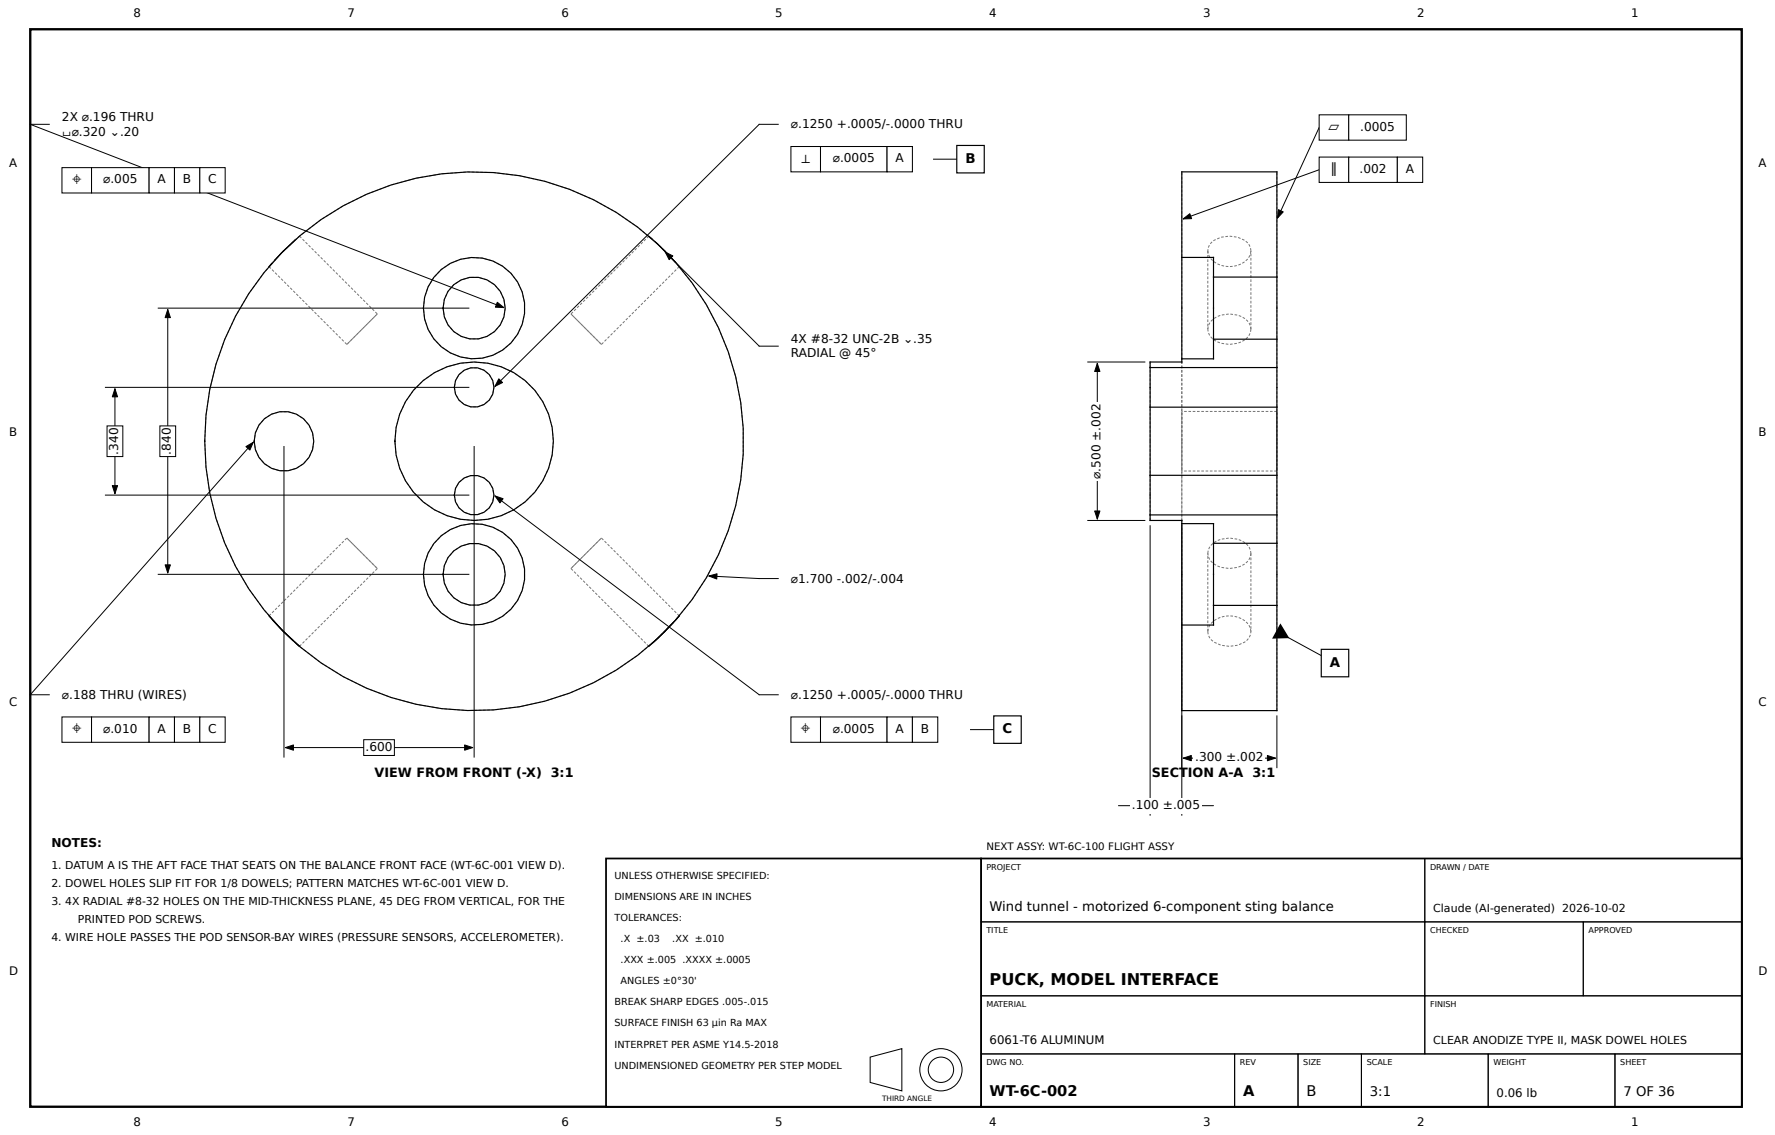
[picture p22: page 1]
VIEW FROM FRONT (-X) 3:1; SECTION A-A 3:1; PROJECT; DRAWN / DATE; TITLE; CHECKED; APPROVED; MATERIAL; 6061-T6 ALUMINUM; FINISH; DWG NO. WT-6C-002; REV A; SIZE B; SCALE; WEIGHT; SHEET; TOLERANCES:; .XXX ±.005 .XXXX ±.0005; ANGLES ±0°30'; THIRD ANGLE; ⌀.1250 +.0005/-.0000 THRU; 2X ⌀.196 THRU ⌴⌀.320 ⌄.20; ⌀.188 THRU (WIRES); 4X #8-32 UNC-2B ⌄.35 RADIAL @ 45°

NOTES:
1. DATUM A IS THE AFT FACE THAT SEATS ON THE BALANCE FRONT FACE (WT-6C-001 VIEW D).
2. DOWEL HOLES SLIP FIT FOR 1/8 DOWELS; PATTERN MATCHES WT-6C-001 VIEW D.
3. 4X RADIAL #8-32 HOLES ON THE MID-THICKNESS PLANE, 45 DEG FROM VERTICAL, FOR THE
PRINTED POD SCREWS.
4. WIRE HOLE PASSES THE POD SENSOR-BAY WIRES (PRESSURE SENSORS, ACCELEROMETER).

NEXT ASSY: WT-6C-100 FLIGHT ASSY

UNLESS OTHERWISE SPECIFIED:

DIMENSIONS ARE IN INCHES

Wind tunnel - motorized 6-component sting balance

Claude (AI-generated) 2026-10-02

PUCK, MODEL INTERFACE

BREAK SHARP EDGES .005-.015

SURFACE FINISH 63 µin Ra MAX

CLEAR ANODIZE TYPE II, MASK DOWEL HOLES

INTERPRET PER ASME Y14.5-2018

UNDIMENSIONED GEOMETRY PER STEP MODEL

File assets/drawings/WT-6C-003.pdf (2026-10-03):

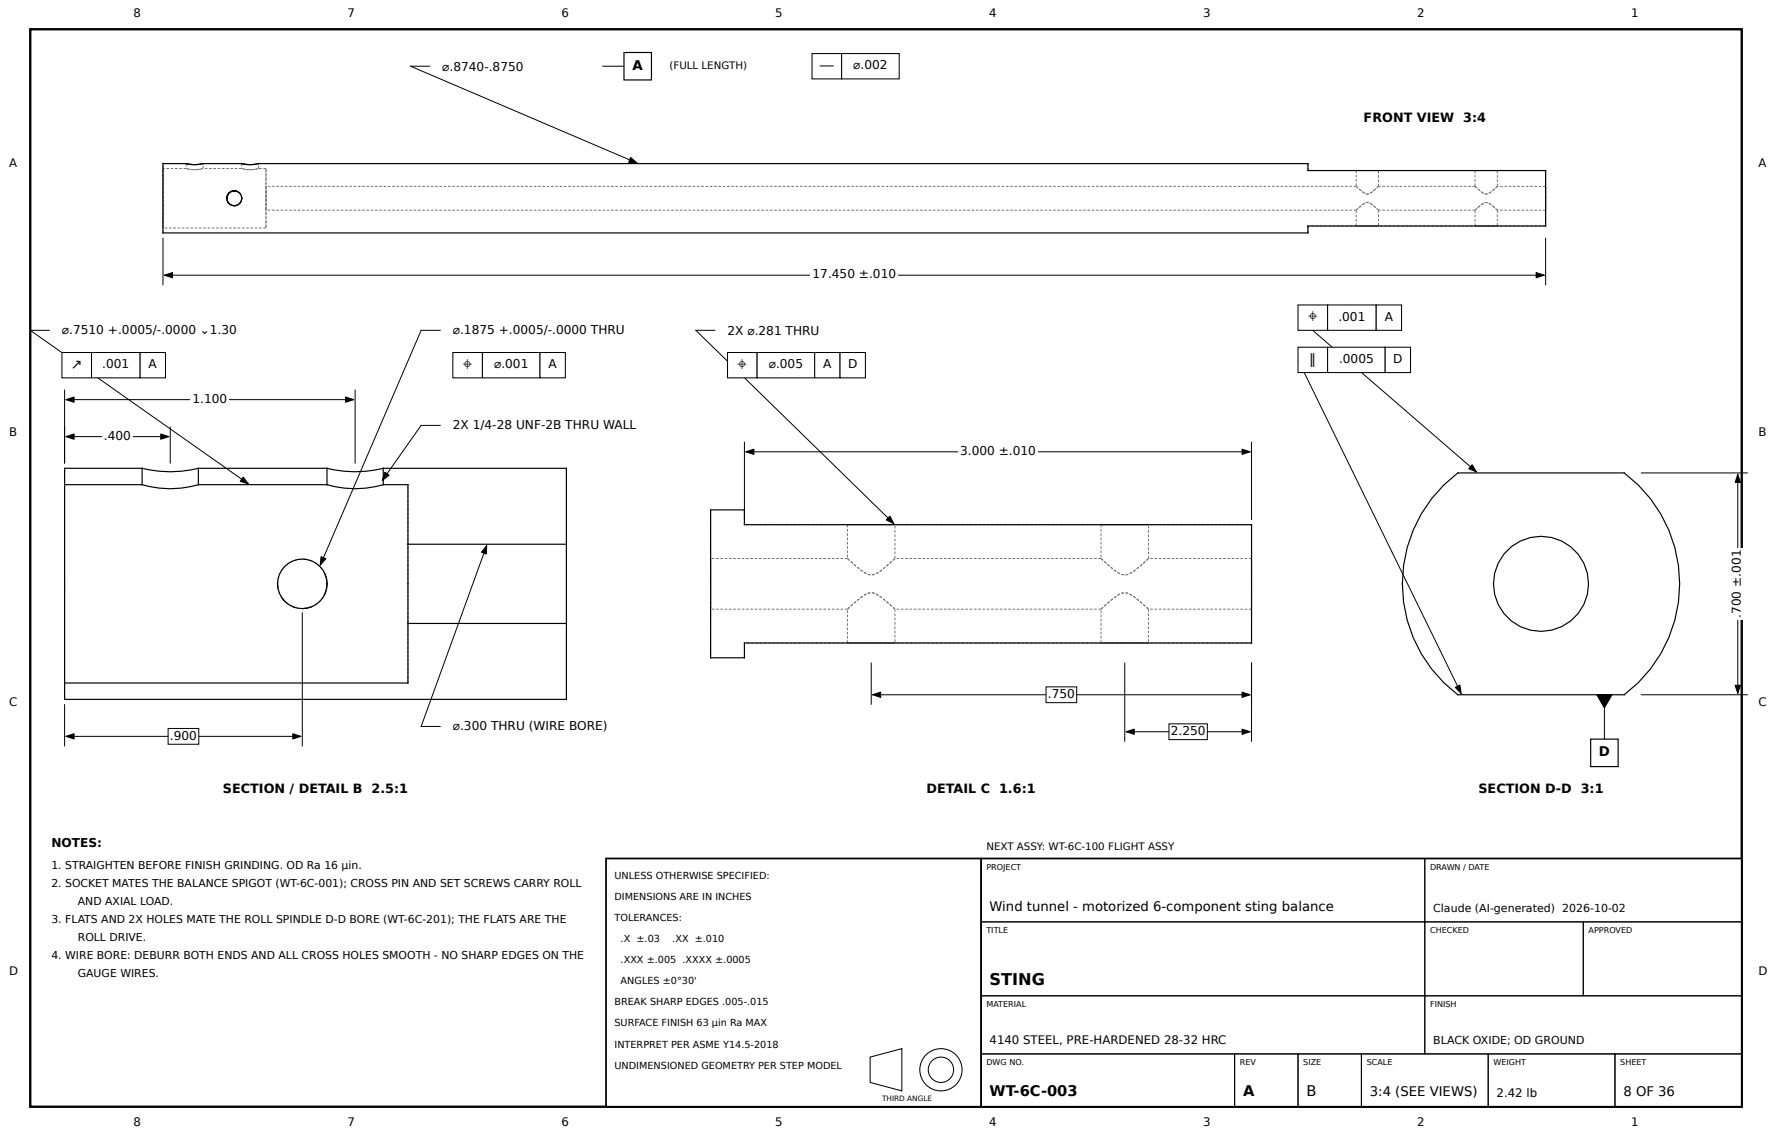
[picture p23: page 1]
FRONT VIEW 3:4; SECTION / DETAIL B 2.5:1; DETAIL C 1.6:1; SECTION D-D 3:1; PROJECT; DRAWN / DATE; TITLE; STING; CHECKED; APPROVED; MATERIAL; FINISH; DWG NO. WT-6C-003; REV A; SIZE B; SCALE; 3:4 (SEE VIEWS); WEIGHT; SHEET; TOLERANCES:; .XXX ±.005 .XXXX ±.0005; ANGLES ±0°30'; THIRD ANGLE; (FULL LENGTH); ⌀.1875 +.0005/-.0000 THRU; 2X ⌀.281 THRU

2X 1/4-28 UNF-2B THRU WALL

⌀.300 THRU (WIRE BORE)

NOTES:
1. STRAIGHTEN BEFORE FINISH GRINDING. OD Ra 16 µin.
2. SOCKET MATES THE BALANCE SPIGOT (WT-6C-001); CROSS PIN AND SET SCREWS CARRY ROLL
AND AXIAL LOAD.
3. FLATS AND 2X HOLES MATE THE ROLL SPINDLE D-D BORE (WT-6C-201); THE FLATS ARE THE
ROLL DRIVE.
4. WIRE BORE: DEBURR BOTH ENDS AND ALL CROSS HOLES SMOOTH - NO SHARP EDGES ON THE
GAUGE WIRES.

NEXT ASSY: WT-6C-100 FLIGHT ASSY

UNLESS OTHERWISE SPECIFIED:

DIMENSIONS ARE IN INCHES

Wind tunnel - motorized 6-component sting balance

Claude (AI-generated) 2026-10-02

BREAK SHARP EDGES .005-.015

SURFACE FINISH 63 µin Ra MAX

4140 STEEL, PRE-HARDENED 28-32 HRC

BLACK OXIDE; OD GROUND

INTERPRET PER ASME Y14.5-2018

UNDIMENSIONED GEOMETRY PER STEP MODEL

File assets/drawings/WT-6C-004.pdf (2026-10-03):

B

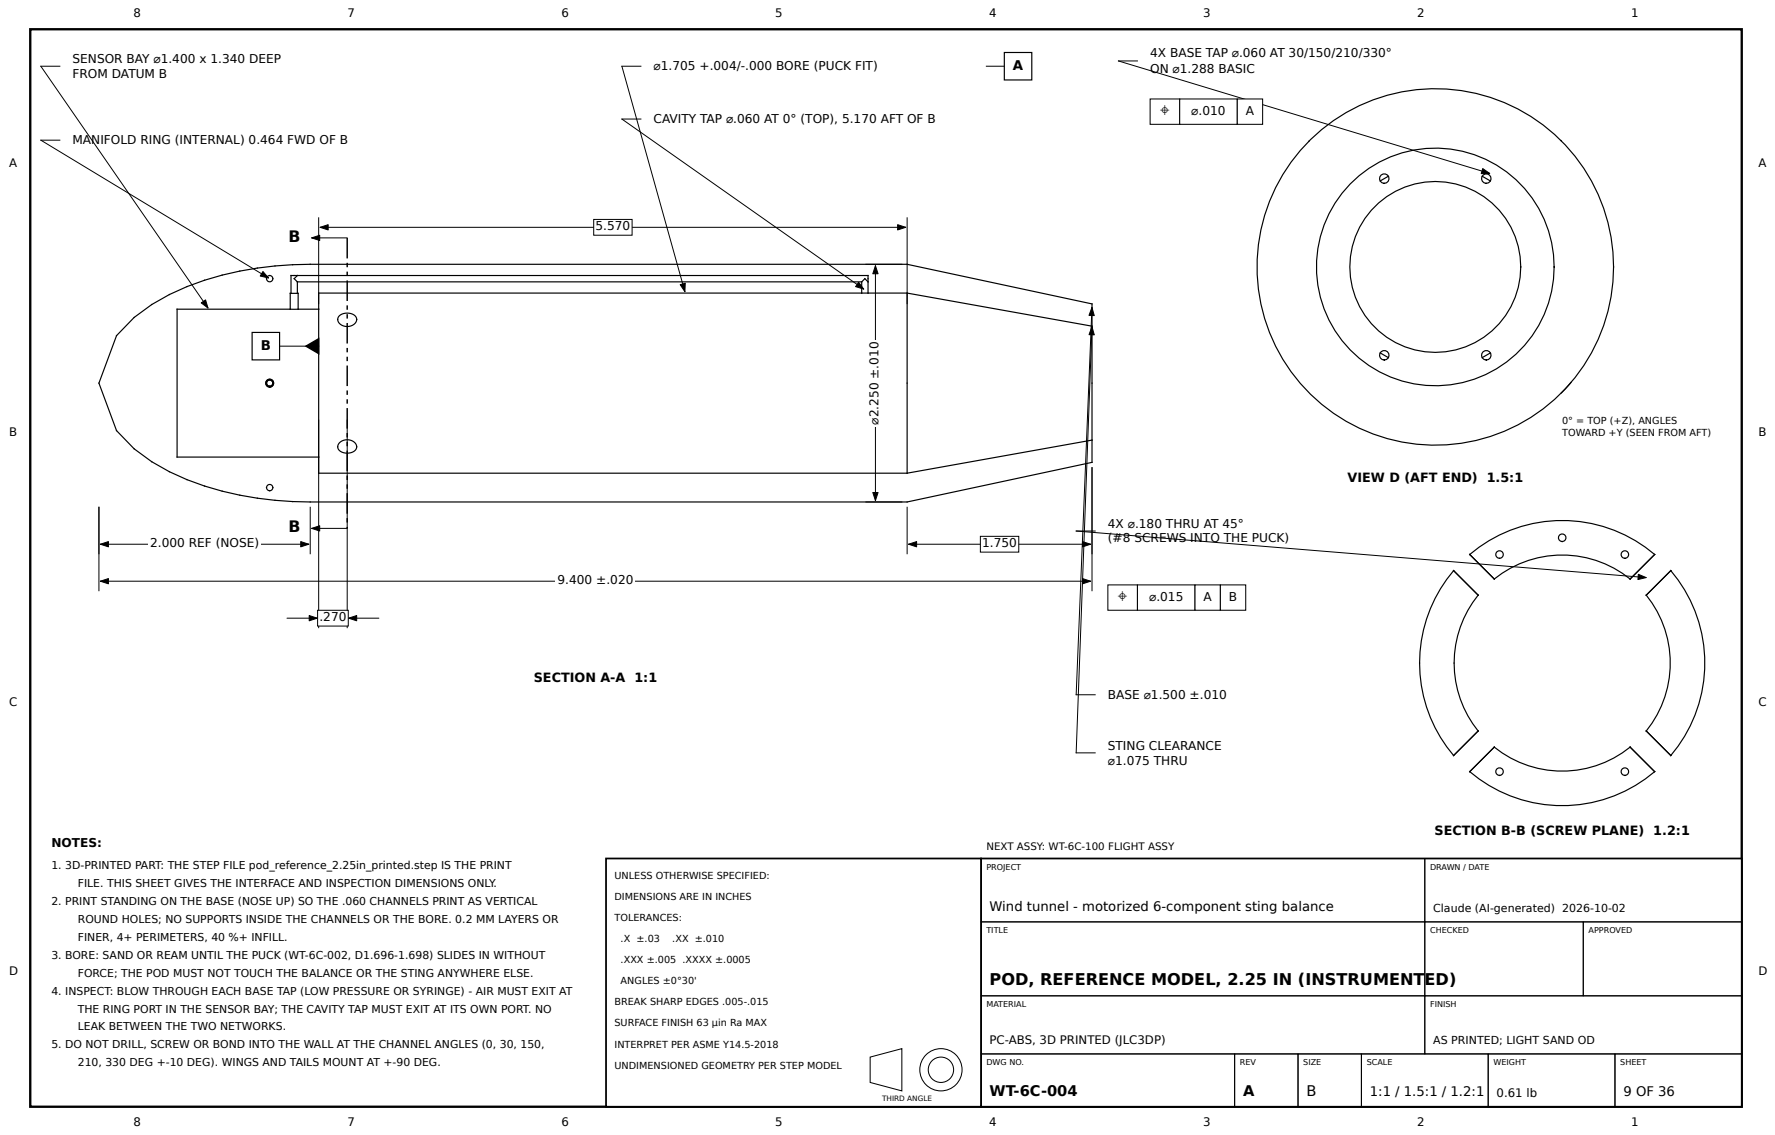
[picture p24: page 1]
SECTION A-A 1:1; PROJECT; DRAWN / DATE; TITLE; CHECKED; APPROVED; MATERIAL; FINISH; DWG NO. WT-6C-004; REV A; SIZE B; SCALE; WEIGHT; SHEET; TOLERANCES:; .XXX ±.005 .XXXX ±.0005; ANGLES ±0°30'; THIRD ANGLE; 2.000 REF (NOSE); BASE ⌀1.500 ±.010; STING CLEARANCE ⌀1.075 THRU

4X BASE TAP ⌀.060 AT 30/150/210/330°
ON ⌀1.288 BASIC

SENSOR BAY ⌀1.400 x 1.340 DEEP
FROM DATUM B

⌀1.705 +.004/-.000 BORE (PUCK FIT)

CAVITY TAP ⌀.060 AT 0° (TOP), 5.170 AFT OF B

MANIFOLD RING (INTERNAL) 0.464 FWD OF B

0° = TOP (+Z), ANGLES
TOWARD +Y (SEEN FROM AFT)

VIEW D (AFT END) 1.5:1

4X ⌀.180 THRU AT 45°
(#8 SCREWS INTO THE PUCK)

SECTION B-B (SCREW PLANE) 1.2:1

NOTES:
1. 3D-PRINTED PART: THE STEP FILE pod_reference_2.25in_printed.step IS THE PRINT
FILE. THIS SHEET GIVES THE INTERFACE AND INSPECTION DIMENSIONS ONLY.
2. PRINT STANDING ON THE BASE (NOSE UP) SO THE .060 CHANNELS PRINT AS VERTICAL
ROUND HOLES; NO SUPPORTS INSIDE THE CHANNELS OR THE BORE. 0.2 MM LAYERS OR
FINER, 4+ PERIMETERS, 40 %+ INFILL.
3. BORE: SAND OR REAM UNTIL THE PUCK (WT-6C-002, D1.696-1.698) SLIDES IN WITHOUT
FORCE; THE POD MUST NOT TOUCH THE BALANCE OR THE STING ANYWHERE ELSE.
4. INSPECT: BLOW THROUGH EACH BASE TAP (LOW PRESSURE OR SYRINGE) - AIR MUST EXIT AT
THE RING PORT IN THE SENSOR BAY; THE CAVITY TAP MUST EXIT AT ITS OWN PORT. NO
LEAK BETWEEN THE TWO NETWORKS.
5. DO NOT DRILL, SCREW OR BOND INTO THE WALL AT THE CHANNEL ANGLES (0, 30, 150,
210, 330 DEG +-10 DEG). WINGS AND TAILS MOUNT AT +-90 DEG.

NEXT ASSY: WT-6C-100 FLIGHT ASSY

UNLESS OTHERWISE SPECIFIED:

DIMENSIONS ARE IN INCHES

Wind tunnel - motorized 6-component sting balance

Claude (AI-generated) 2026-10-02

POD, REFERENCE MODEL, 2.25 IN (INSTRUMENTED)

BREAK SHARP EDGES .005-.015

SURFACE FINISH 63 µin Ra MAX

PC-ABS, 3D PRINTED (JLC3DP)

AS PRINTED; LIGHT SAND OD

INTERPRET PER ASME Y14.5-2018

UNDIMENSIONED GEOMETRY PER STEP MODEL

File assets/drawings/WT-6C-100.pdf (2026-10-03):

8

7

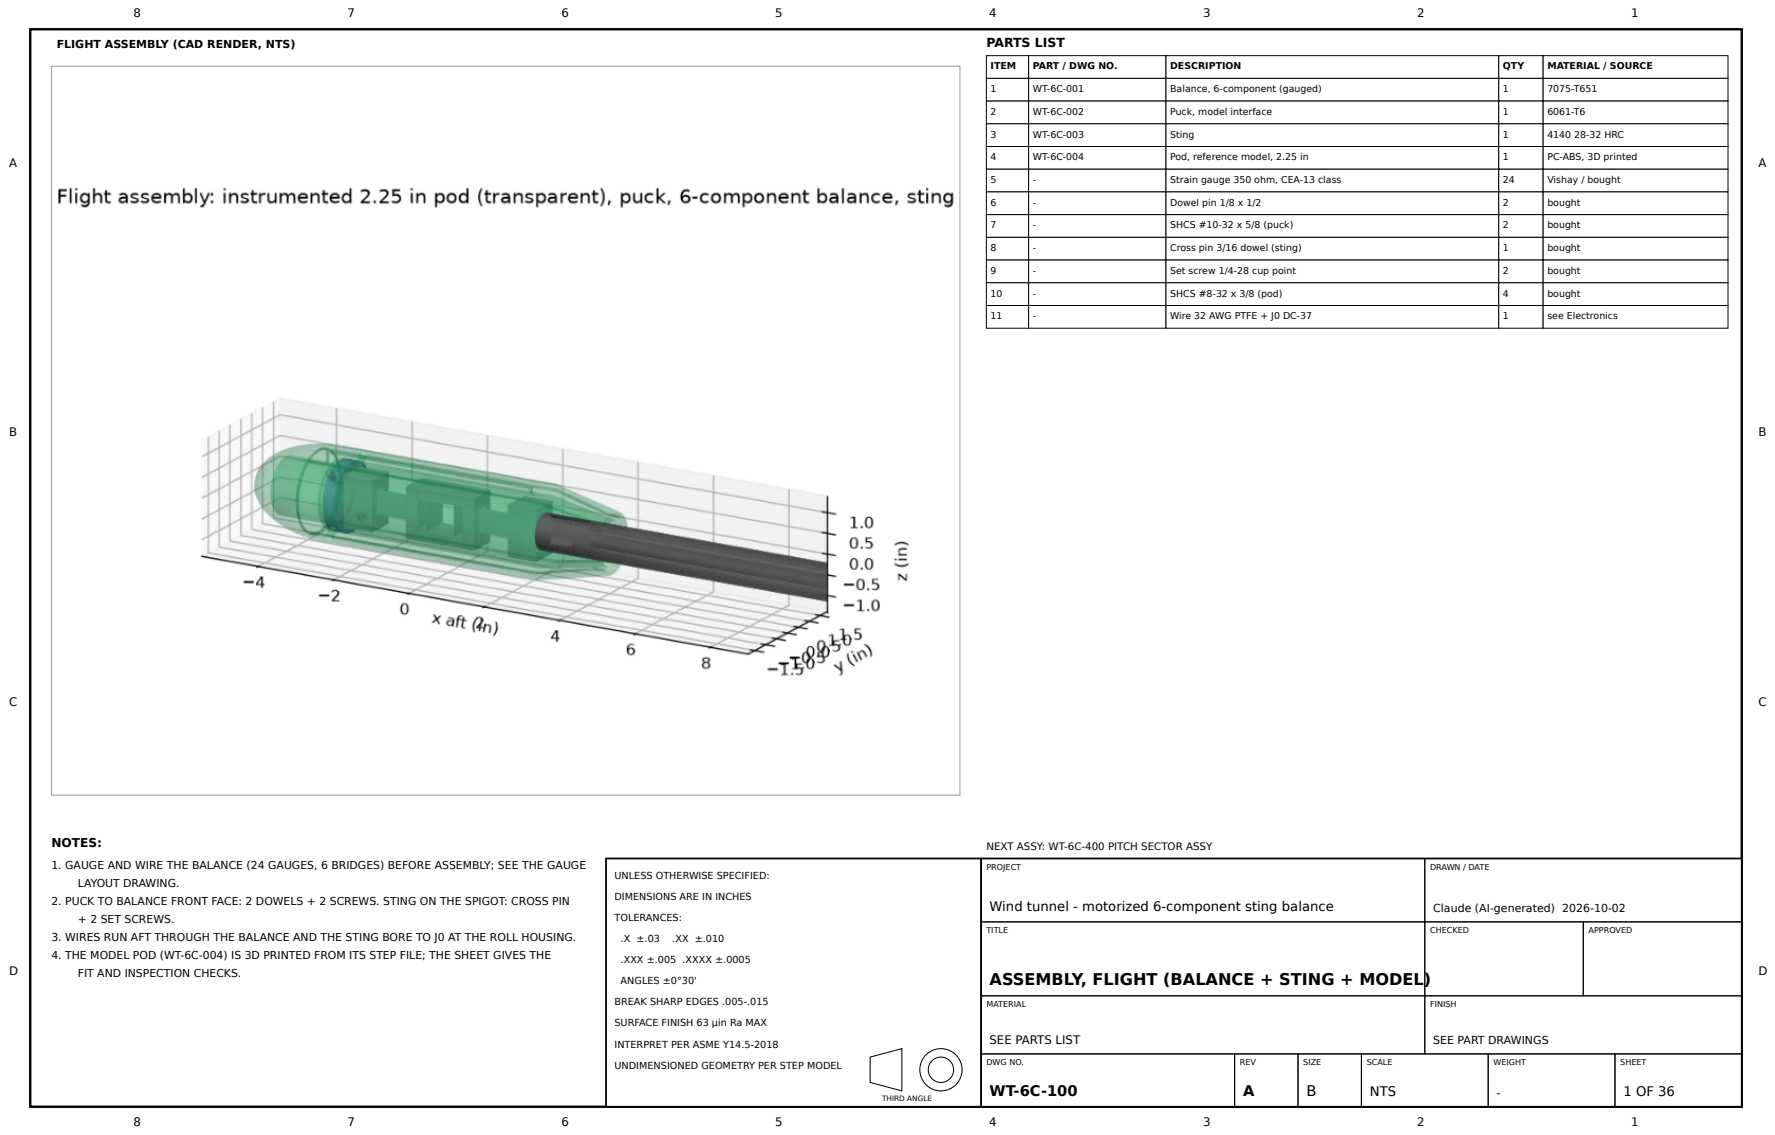
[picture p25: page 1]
NOTES:; NEXT ASSY: WT-6C-400 PITCH SECTOR ASSY; FLIGHT ASSEMBLY (CAD RENDER, NTS); PARTS LIST

ITEM | PART / DWG NO. | DESCRIPTION | QTY | MATERIAL / SOURCE

1 | WT-6C-001 | Balance, 6-component (gauged) | 1 | 7075-T651

2 | WT-6C-002 | Puck, model interface | 1 | 6061-T6

3 | WT-6C-003 | Sting | 1 | 4140 28-32 HRC

4 | WT-6C-004 | Pod, reference model, 2.25 in | 1 | PC-ABS, 3D printed

5 | - | Strain gauge 350 ohm, CEA-13 class | 24 | Vishay / bought

6 | - | Dowel pin 1/8 x 1/2 | 2 | bought

7 | - | SHCS #10-32 x 5/8 (puck) | 2 | bought

8 | - | Cross pin 3/16 dowel (sting) | 1 | bought

9 | - | Set screw 1/4-28 cup point | 2 | bought

10 | - | SHCS #8-32 x 3/8 (pod) | 4 | bought

11 | - | Wire 32 AWG PTFE + J0 DC-37 | 1 | see Electronics

1. GAUGE AND WIRE THE BALANCE (24 GAUGES, 6 BRIDGES) BEFORE ASSEMBLY; SEE THE GAUGE
LAYOUT DRAWING.
2. PUCK TO BALANCE FRONT FACE: 2 DOWELS + 2 SCREWS. STING ON THE SPIGOT: CROSS PIN
+ 2 SET SCREWS.
3. WIRES RUN AFT THROUGH THE BALANCE AND THE STING BORE TO J0 AT THE ROLL HOUSING.
4. THE MODEL POD (WT-6C-004) IS 3D PRINTED FROM ITS STEP FILE; THE SHEET GIVES THE
FIT AND INSPECTION CHECKS.

UNLESS OTHERWISE SPECIFIED: DIMENSIONS ARE IN INCHES TOLERANCES: .X ±.03 .XX ±.010 .XXX ±.005 .XXXX ±.0005 ANGLES ±0°30' BREAK SHARP EDGES .005-.015 SURFACE FINISH 63 µin Ra MAX INTERPRET PER ASME Y14.5-2018 UNDIMENSIONED GEOMETRY PER STEP MODEL THIRD ANGLE | PROJECT Wind tunnel - motorized 6-component sting balance | DRAWN / DATE Claude (AI-generated) 2026-10-02

TITLE ASSEMBLY, FLIGHT (BALANCE + STING + MODEL) | CHECKED | APPROVED

MATERIAL SEE PARTS LIST | FINISH SEE PART DRAWINGS

DWG NO. WT-6C-100 | REV A | SIZE B | SCALE NTS | WEIGHT - | SHEET

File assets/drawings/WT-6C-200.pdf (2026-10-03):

8

7

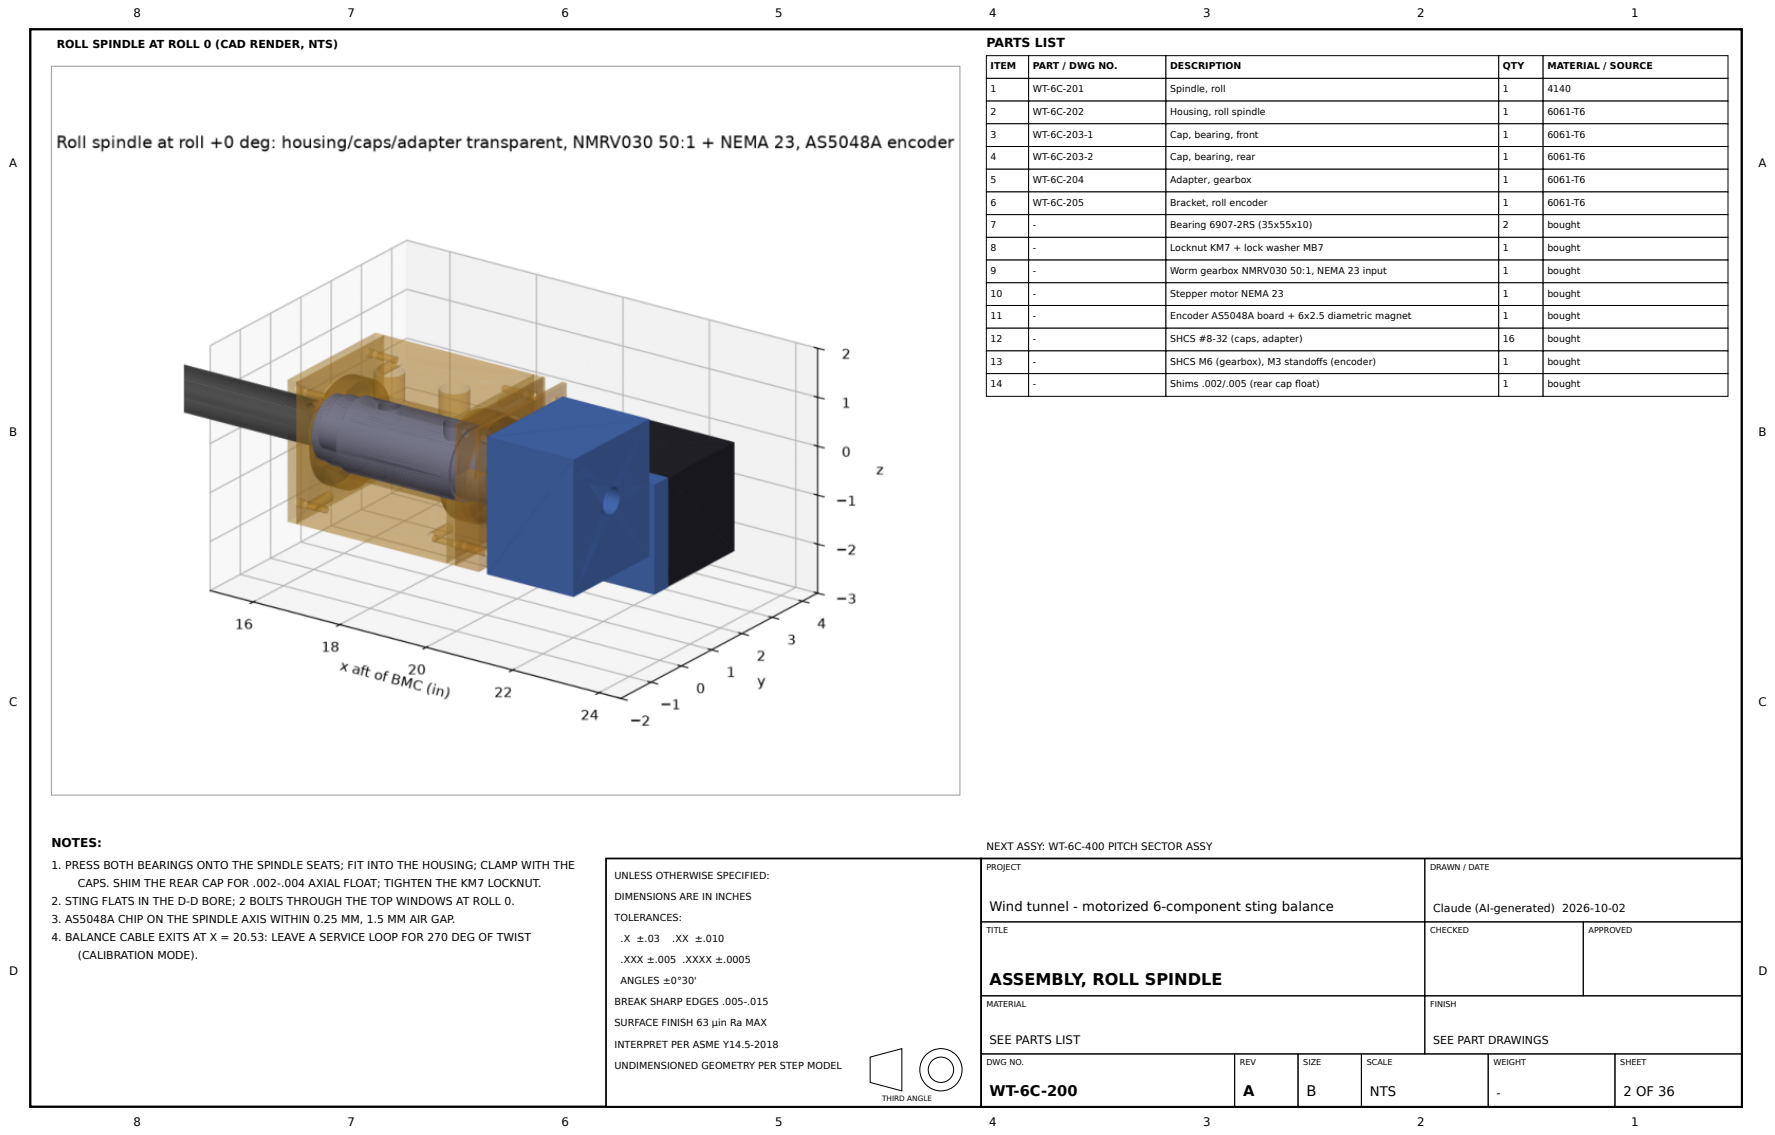
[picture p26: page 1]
NOTES:; NEXT ASSY: WT-6C-400 PITCH SECTOR ASSY; ROLL SPINDLE AT ROLL 0 (CAD RENDER, NTS); PARTS LIST

ITEM | PART / DWG NO. | DESCRIPTION | QTY | MATERIAL / SOURCE

1 | WT-6C-201 | Spindle, roll | 1 | 4140

2 | WT-6C-202 | Housing, roll spindle | 1 | 6061-T6

3 | WT-6C-203-1 | Cap, bearing, front | 1 | 6061-T6

4 | WT-6C-203-2 | Cap, bearing, rear | 1 | 6061-T6

5 | WT-6C-204 | Adapter, gearbox | 1 | 6061-T6

6 | WT-6C-205 | Bracket, roll encoder | 1 | 6061-T6

7 | - | Bearing 6907-2RS (35x55x10) | 2 | bought

8 | - | Locknut KM7 + lock washer MB7 | 1 | bought

9 | - | Worm gearbox NMRV030 50:1, NEMA 23 input | 1 | bought

10 | - | Stepper motor NEMA 23 | 1 | bought

11 | - | Encoder AS5048A board + 6x2.5 diametric magnet | 1 | bought

12 | - | SHCS #8-32 (caps, adapter) | 16 | bought

13 | - | SHCS M6 (gearbox), M3 standoffs (encoder) | 1 | bought

14 | - | Shims .002/.005 (rear cap float) | 1 | bought

1. PRESS BOTH BEARINGS ONTO THE SPINDLE SEATS; FIT INTO THE HOUSING; CLAMP WITH THE
CAPS. SHIM THE REAR CAP FOR .002-.004 AXIAL FLOAT; TIGHTEN THE KM7 LOCKNUT.
2. STING FLATS IN THE D-D BORE; 2 BOLTS THROUGH THE TOP WINDOWS AT ROLL 0.
3. AS5048A CHIP ON THE SPINDLE AXIS WITHIN 0.25 MM, 1.5 MM AIR GAP.
4. BALANCE CABLE EXITS AT X = 20.53: LEAVE A SERVICE LOOP FOR 270 DEG OF TWIST
(CALIBRATION MODE).

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

TITLE ASSEMBLY, ROLL SPINDLE | CHECKED | APPROVED

MATERIAL SEE PARTS LIST | FINISH SEE PART DRAWINGS

DWG NO. WT-6C-200 | REV A | SIZE B | SCALE NTS | WEIGHT - | SHEET

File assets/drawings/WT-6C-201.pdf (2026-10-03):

B

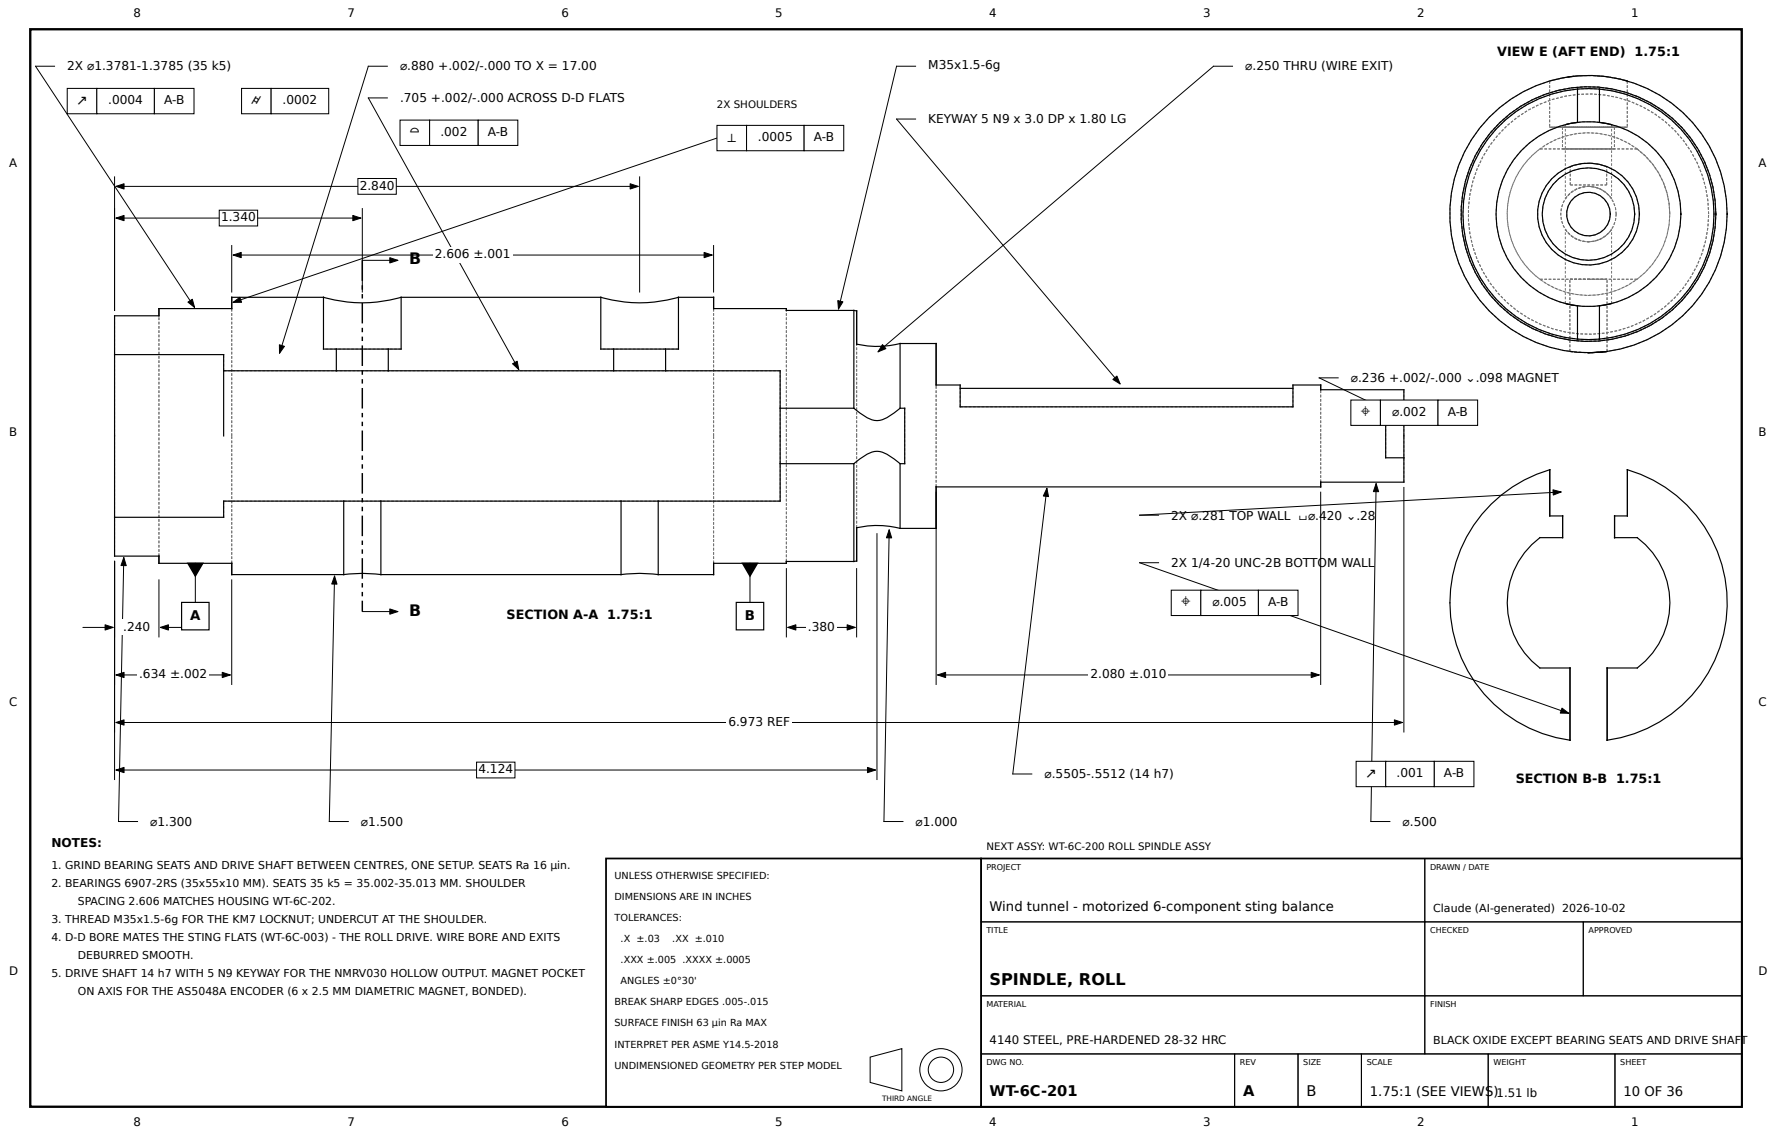
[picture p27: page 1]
SECTION A-A 1.75:1; SECTION B-B 1.75:1; PROJECT; DRAWN / DATE; TITLE; SPINDLE, ROLL; CHECKED; APPROVED; MATERIAL; FINISH; DWG NO. WT-6C-201; REV A; SIZE B; SCALE; 1.75:1 (SEE VIEWS); WEIGHT; SHEET; TOLERANCES:; .XXX ±.005 .XXXX ±.0005; ANGLES ±0°30'; THIRD ANGLE; .705 +.002/-.000 ACROSS D-D FLATS; 2X SHOULDERS; 6.973 REF; ⌀.236 +.002/-.000 ⌄.098 MAGNET; 2X ⌀.281 TOP WALL ⌴⌀.420 ⌄.28

VIEW E (AFT END) 1.75:1

⌀.250 THRU (WIRE EXIT)

KEYWAY 5 N9 x 3.0 DP x 1.80 LG

2X 1/4-20 UNC-2B BOTTOM WALL

NOTES:
1. GRIND BEARING SEATS AND DRIVE SHAFT BETWEEN CENTRES, ONE SETUP. SEATS Ra 16 µin.
2. BEARINGS 6907-2RS (35x55x10 MM). SEATS 35 k5 = 35.002-35.013 MM. SHOULDER
SPACING 2.606 MATCHES HOUSING WT-6C-202.
3. THREAD M35x1.5-6g FOR THE KM7 LOCKNUT; UNDERCUT AT THE SHOULDER.
4. D-D BORE MATES THE STING FLATS (WT-6C-003) - THE ROLL DRIVE. WIRE BORE AND EXITS
DEBURRED SMOOTH.
5. DRIVE SHAFT 14 h7 WITH 5 N9 KEYWAY FOR THE NMRV030 HOLLOW OUTPUT. MAGNET POCKET
ON AXIS FOR THE AS5048A ENCODER (6 x 2.5 MM DIAMETRIC MAGNET, BONDED).

NEXT ASSY: WT-6C-200 ROLL SPINDLE ASSY

UNLESS OTHERWISE SPECIFIED:

DIMENSIONS ARE IN INCHES

Wind tunnel - motorized 6-component sting balance

Claude (AI-generated) 2026-10-02

BREAK SHARP EDGES .005-.015

SURFACE FINISH 63 µin Ra MAX

4140 STEEL, PRE-HARDENED 28-32 HRC

BLACK OXIDE EXCEPT BEARING SEATS AND DRIVE SHAFT

INTERPRET PER ASME Y14.5-2018

UNDIMENSIONED GEOMETRY PER STEP MODEL

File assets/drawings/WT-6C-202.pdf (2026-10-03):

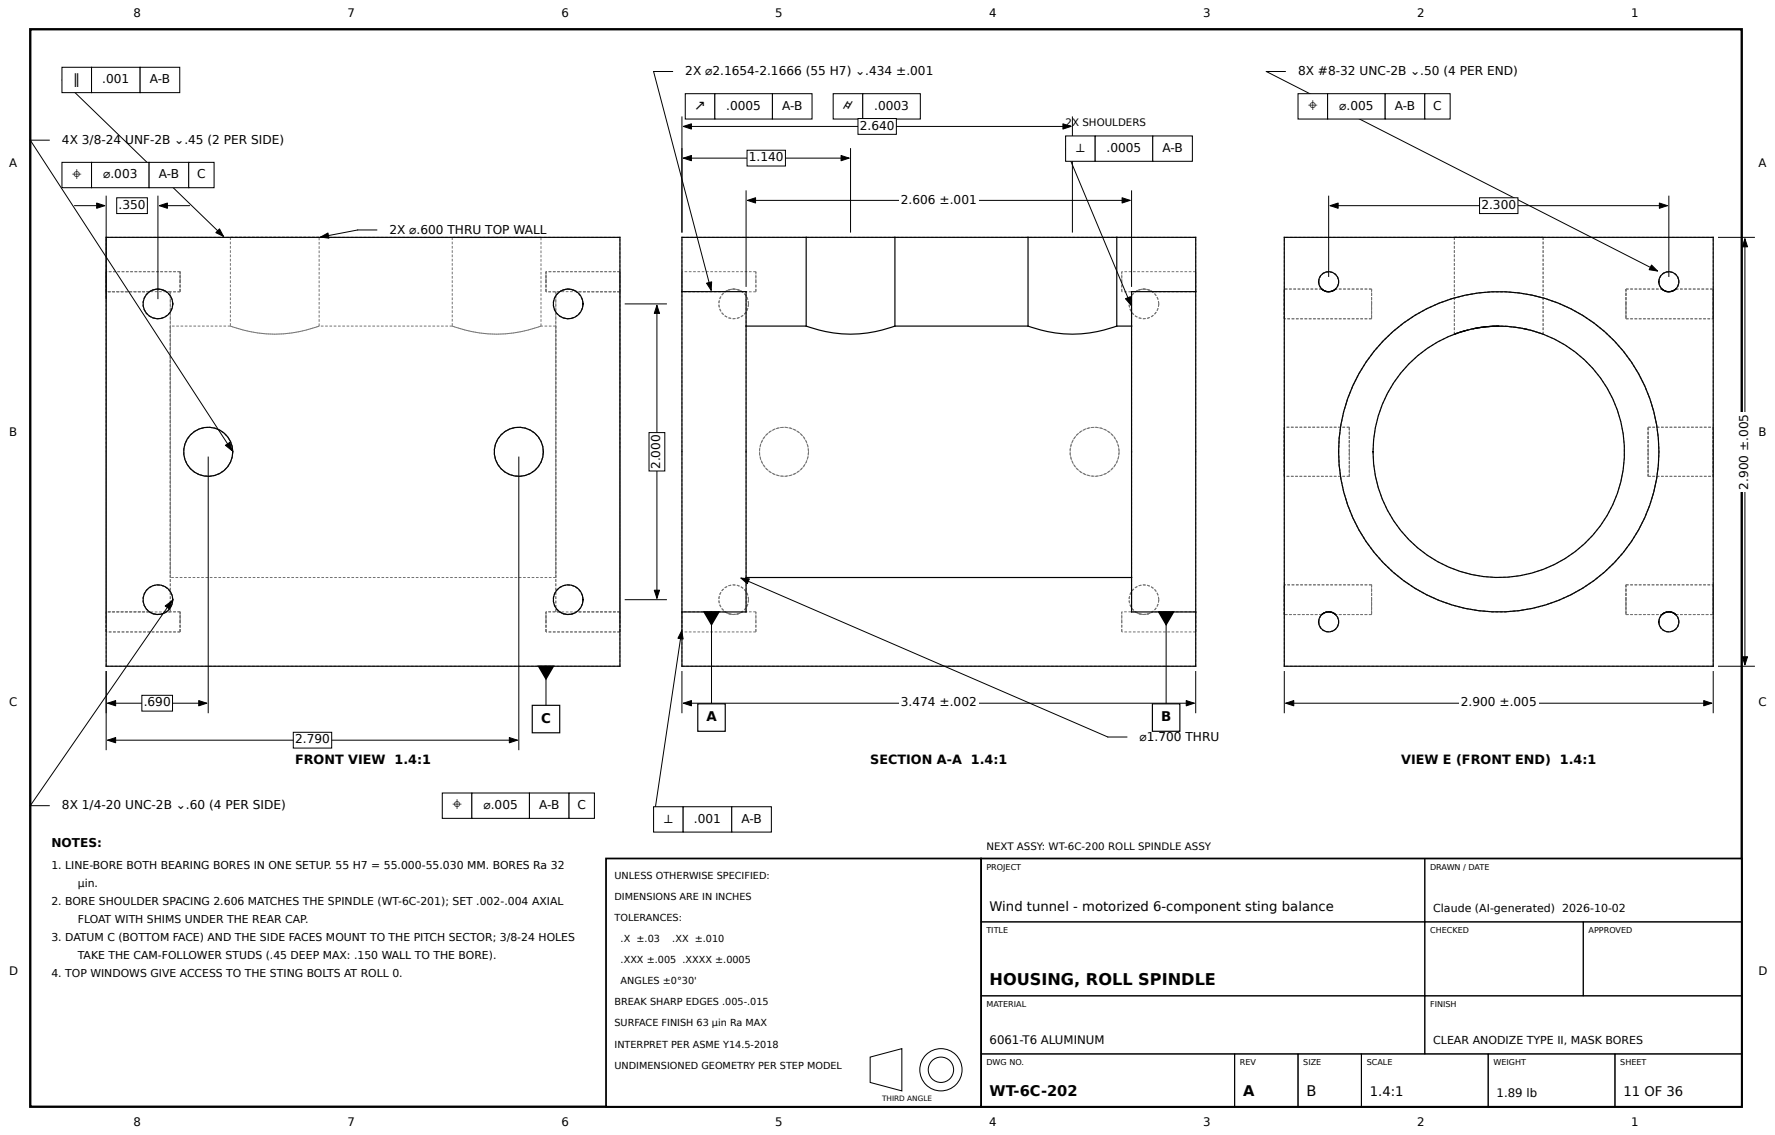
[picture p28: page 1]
FRONT VIEW 1.4:1; SECTION A-A 1.4:1; VIEW E (FRONT END) 1.4:1; PROJECT; DRAWN / DATE; TITLE; CHECKED; APPROVED; MATERIAL; 6061-T6 ALUMINUM; FINISH; DWG NO. WT-6C-202; REV A; SIZE B; SCALE; WEIGHT; SHEET; TOLERANCES:; .XXX ±.005 .XXXX ±.0005; ANGLES ±0°30'; THIRD ANGLE; 2X SHOULDERS; ⌀1.700 THRU

8X #8-32 UNC-2B ⌄.50 (4 PER END)

4X 3/8-24 UNF-2B ⌄.45 (2 PER SIDE)

2X ⌀.600 THRU TOP WALL

8X 1/4-20 UNC-2B ⌄.60 (4 PER SIDE)

NOTES:
1. LINE-BORE BOTH BEARING BORES IN ONE SETUP. 55 H7 = 55.000-55.030 MM. BORES Ra 32
µin.
2. BORE SHOULDER SPACING 2.606 MATCHES THE SPINDLE (WT-6C-201); SET .002-.004 AXIAL
FLOAT WITH SHIMS UNDER THE REAR CAP.
3. DATUM C (BOTTOM FACE) AND THE SIDE FACES MOUNT TO THE PITCH SECTOR; 3/8-24 HOLES
TAKE THE CAM-FOLLOWER STUDS (.45 DEEP MAX: .150 WALL TO THE BORE).
4. TOP WINDOWS GIVE ACCESS TO THE STING BOLTS AT ROLL 0.

NEXT ASSY: WT-6C-200 ROLL SPINDLE ASSY

UNLESS OTHERWISE SPECIFIED:

DIMENSIONS ARE IN INCHES

Wind tunnel - motorized 6-component sting balance

Claude (AI-generated) 2026-10-02

HOUSING, ROLL SPINDLE

BREAK SHARP EDGES .005-.015

SURFACE FINISH 63 µin Ra MAX

CLEAR ANODIZE TYPE II, MASK BORES

INTERPRET PER ASME Y14.5-2018

UNDIMENSIONED GEOMETRY PER STEP MODEL

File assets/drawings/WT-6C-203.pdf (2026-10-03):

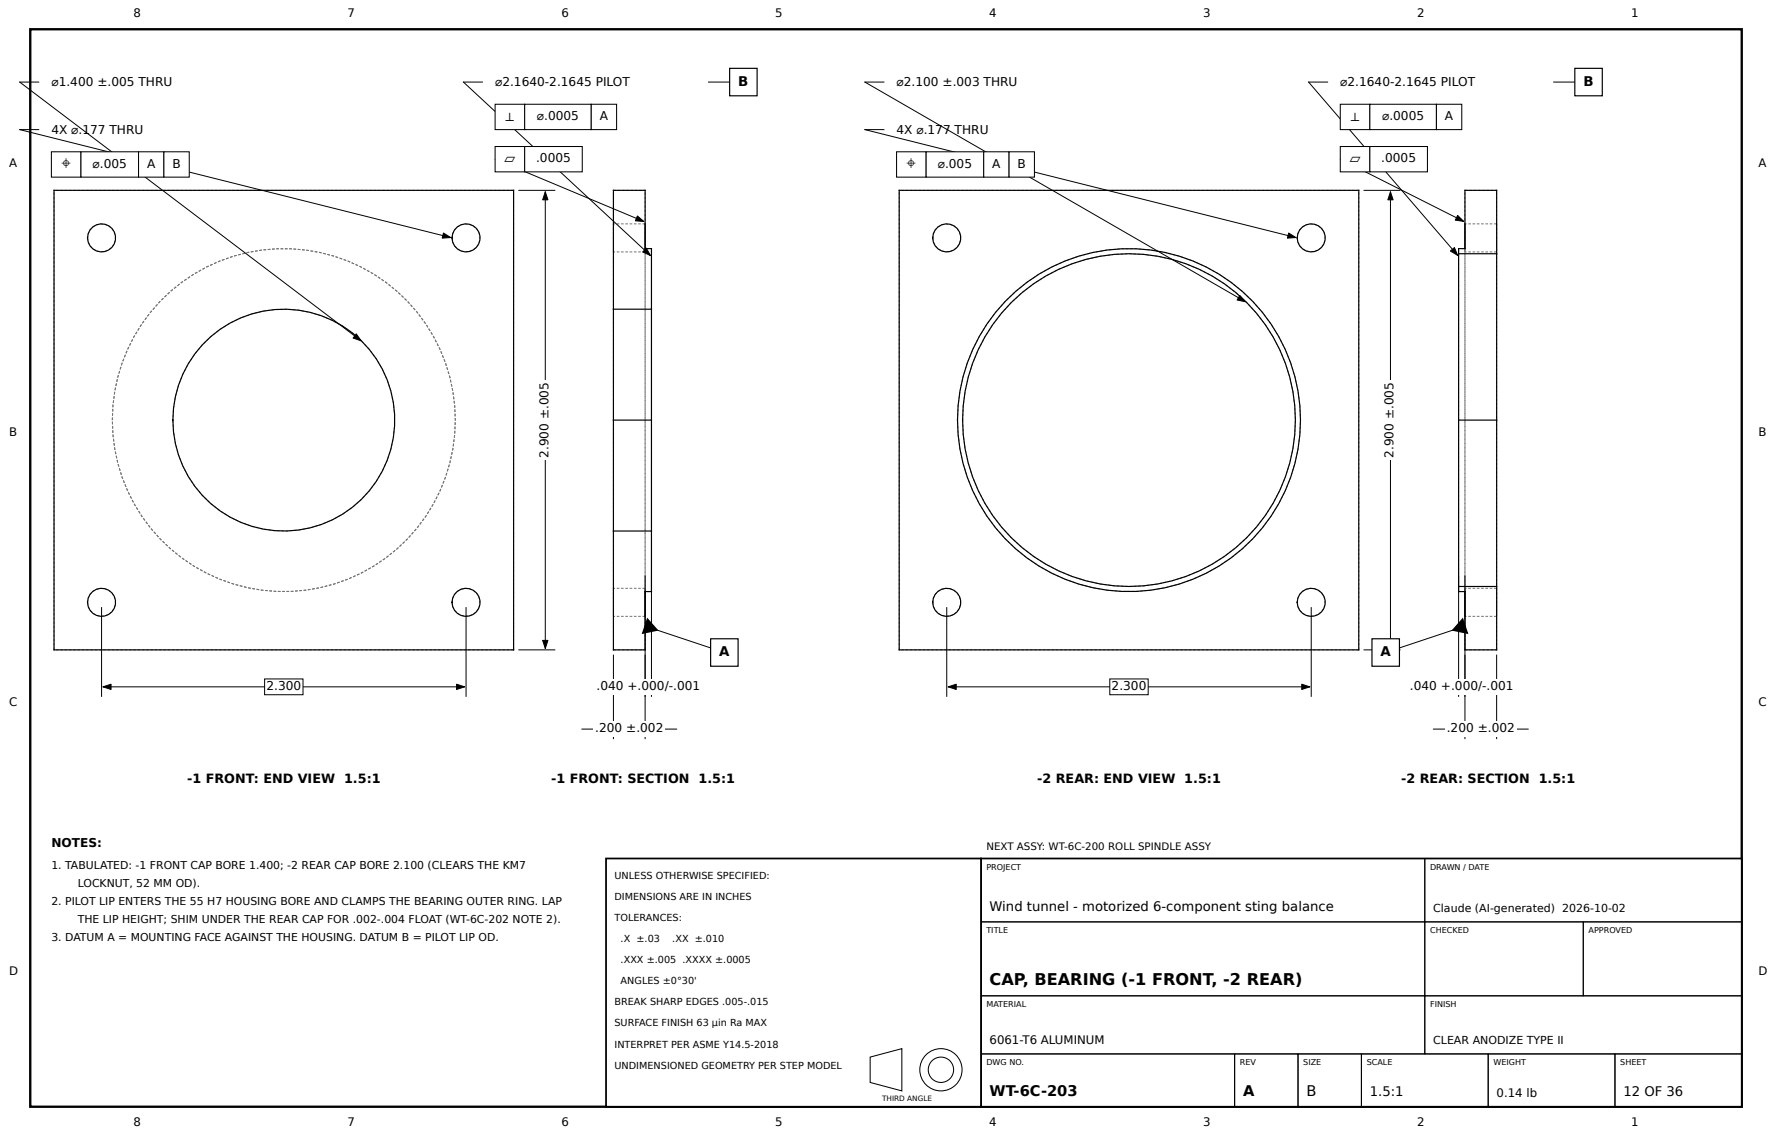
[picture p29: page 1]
-1 FRONT: END VIEW 1.5:1; -1 FRONT: SECTION 1.5:1; -2 REAR: END VIEW 1.5:1; -2 REAR: SECTION 1.5:1; PROJECT; DRAWN / DATE; TITLE; CHECKED; APPROVED; MATERIAL; 6061-T6 ALUMINUM; FINISH; DWG NO. WT-6C-203; REV A; SIZE B; SCALE; WEIGHT; SHEET; TOLERANCES:; .XXX ±.005 .XXXX ±.0005; ANGLES ±0°30'; THIRD ANGLE; ⌀2.1640-2.1645 PILOT; ⌀1.400 ±.005 THRU; 4X ⌀.177 THRU; ⌀2.100 ±.003 THRU

NOTES:
1. TABULATED: -1 FRONT CAP BORE 1.400; -2 REAR CAP BORE 2.100 (CLEARS THE KM7
LOCKNUT, 52 MM OD).
2. PILOT LIP ENTERS THE 55 H7 HOUSING BORE AND CLAMPS THE BEARING OUTER RING. LAP
THE LIP HEIGHT; SHIM UNDER THE REAR CAP FOR .002-.004 FLOAT (WT-6C-202 NOTE 2).
3. DATUM A = MOUNTING FACE AGAINST THE HOUSING. DATUM B = PILOT LIP OD.

NEXT ASSY: WT-6C-200 ROLL SPINDLE ASSY

UNLESS OTHERWISE SPECIFIED:

DIMENSIONS ARE IN INCHES

Wind tunnel - motorized 6-component sting balance

Claude (AI-generated) 2026-10-02

CAP, BEARING (-1 FRONT, -2 REAR)

BREAK SHARP EDGES .005-.015

SURFACE FINISH 63 µin Ra MAX

CLEAR ANODIZE TYPE II

INTERPRET PER ASME Y14.5-2018

UNDIMENSIONED GEOMETRY PER STEP MODEL

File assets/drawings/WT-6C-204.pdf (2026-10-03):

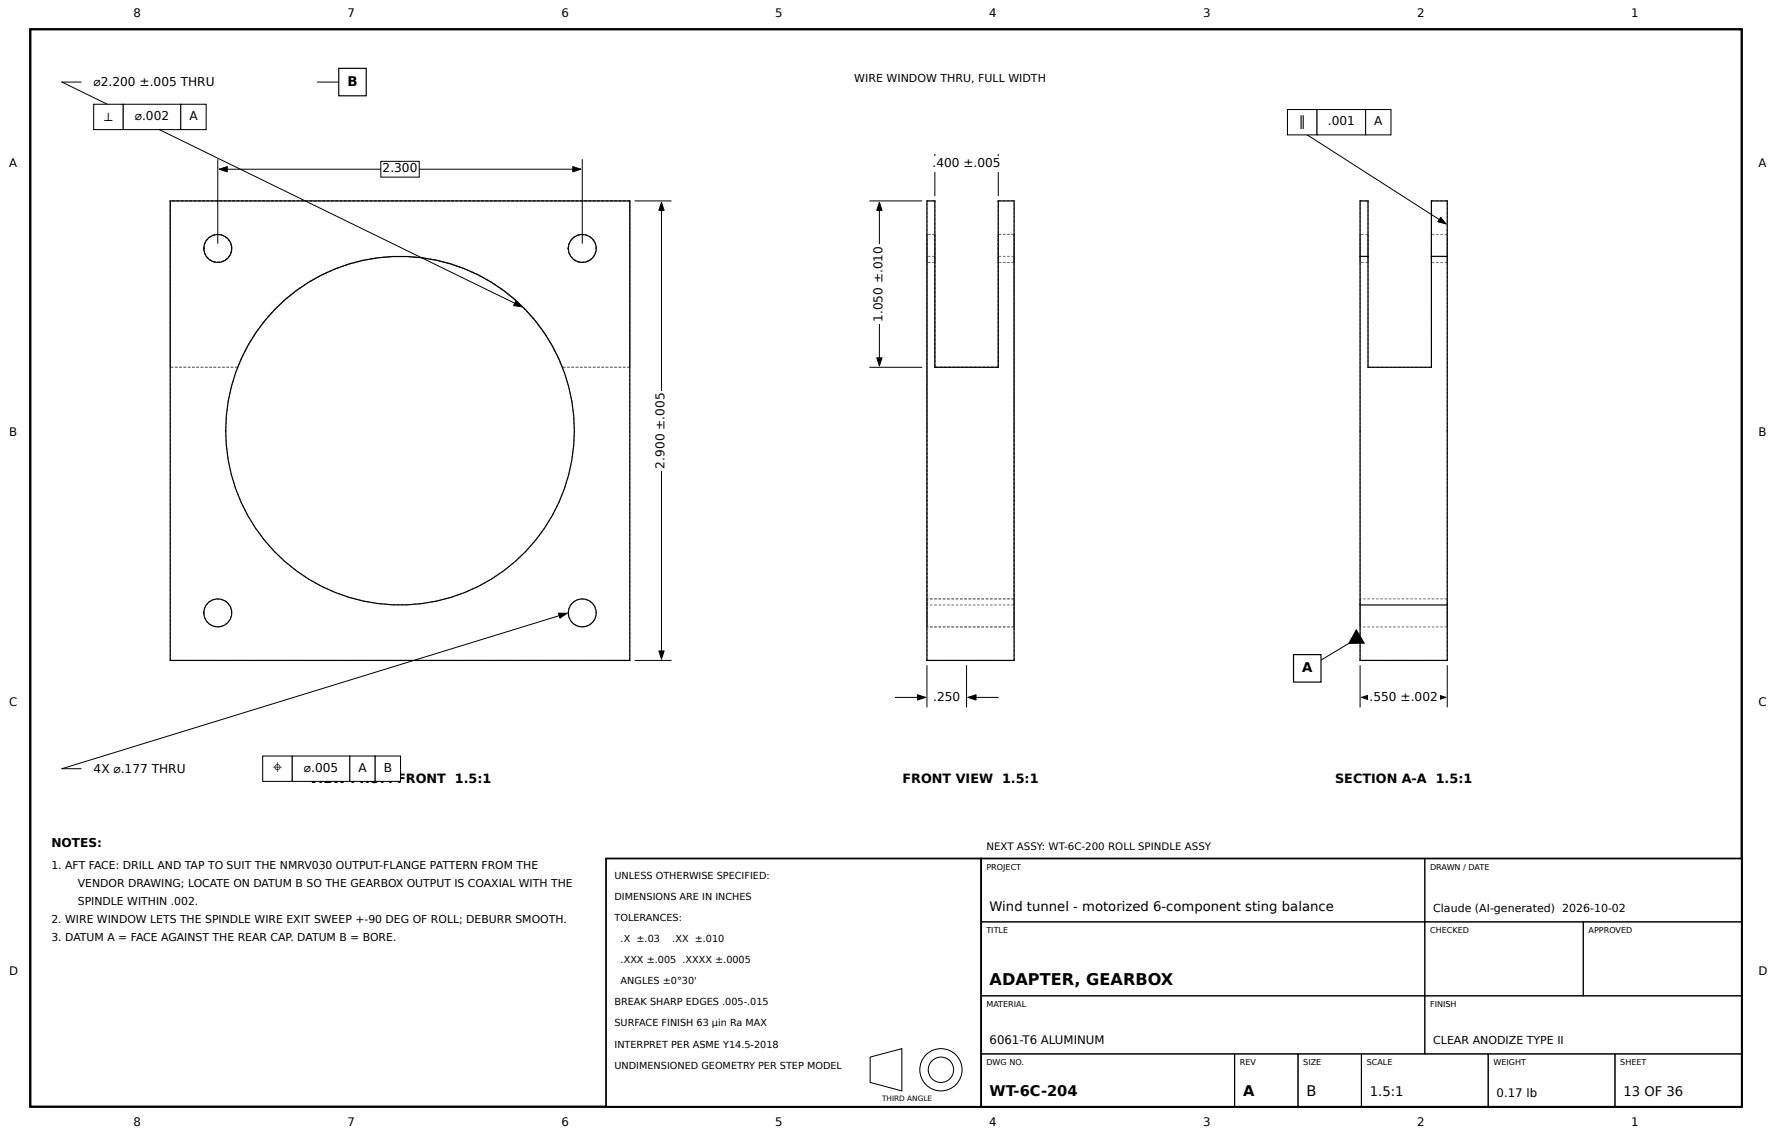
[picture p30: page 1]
VIEW FROM FRONT 1.5:1; FRONT VIEW 1.5:1; SECTION A-A 1.5:1; PROJECT; DRAWN / DATE; TITLE; ADAPTER, GEARBOX; CHECKED; APPROVED; MATERIAL; 6061-T6 ALUMINUM; FINISH; DWG NO. WT-6C-204; REV A; SIZE B; SCALE; WEIGHT; SHEET; TOLERANCES:; .XXX ±.005 .XXXX ±.0005; ANGLES ±0°30'; THIRD ANGLE; ⌀2.200 ±.005 THRU; 4X ⌀.177 THRU

WIRE WINDOW THRU, FULL WIDTH

NOTES:
1. AFT FACE: DRILL AND TAP TO SUIT THE NMRV030 OUTPUT-FLANGE PATTERN FROM THE
VENDOR DRAWING; LOCATE ON DATUM B SO THE GEARBOX OUTPUT IS COAXIAL WITH THE
SPINDLE WITHIN .002.
2. WIRE WINDOW LETS THE SPINDLE WIRE EXIT SWEEP +-90 DEG OF ROLL; DEBURR SMOOTH.
3. DATUM A = FACE AGAINST THE REAR CAP. DATUM B = BORE.

NEXT ASSY: WT-6C-200 ROLL SPINDLE ASSY

UNLESS OTHERWISE SPECIFIED:

DIMENSIONS ARE IN INCHES

Wind tunnel - motorized 6-component sting balance

Claude (AI-generated) 2026-10-02

BREAK SHARP EDGES .005-.015

SURFACE FINISH 63 µin Ra MAX

CLEAR ANODIZE TYPE II

INTERPRET PER ASME Y14.5-2018

UNDIMENSIONED GEOMETRY PER STEP MODEL

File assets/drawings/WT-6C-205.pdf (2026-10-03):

# 2X SLOT .22 WIDE x .45 LG 1.160

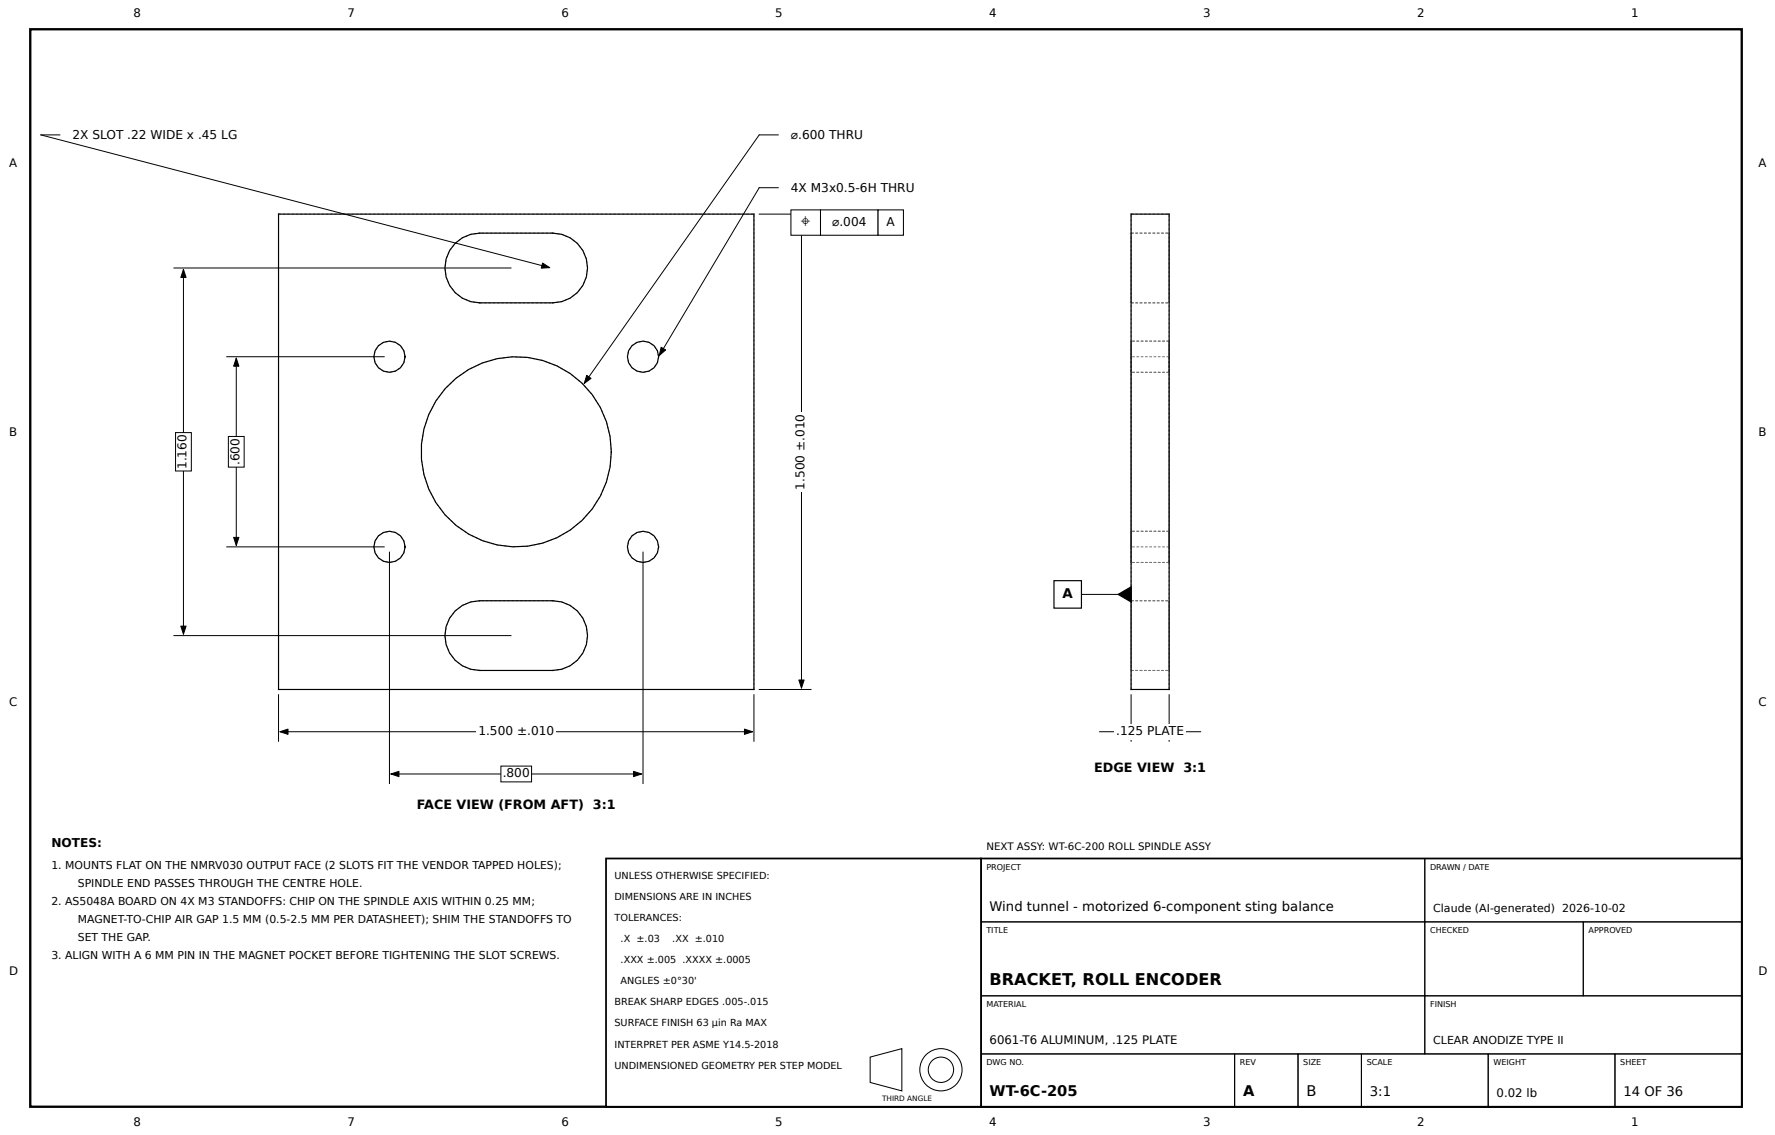
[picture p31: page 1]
EDGE VIEW 3:1; PROJECT; DRAWN / DATE; TITLE; CHECKED; APPROVED; MATERIAL; 6061-T6 ALUMINUM, .125 PLATE; FINISH; DWG NO. WT-6C-205; REV A; SIZE B; SCALE; WEIGHT; SHEET; TOLERANCES:; .XXX ±.005 .XXXX ±.0005; ANGLES ±0°30'; THIRD ANGLE; ⌀.600 THRU; 4X M3x0.5-6H THRU; .125 PLATE

FACE VIEW (FROM AFT) 3:1

NOTES:
1. MOUNTS FLAT ON THE NMRV030 OUTPUT FACE (2 SLOTS FIT THE VENDOR TAPPED HOLES);
SPINDLE END PASSES THROUGH THE CENTRE HOLE.
2. AS5048A BOARD ON 4X M3 STANDOFFS: CHIP ON THE SPINDLE AXIS WITHIN 0.25 MM;
MAGNET-TO-CHIP AIR GAP 1.5 MM (0.5-2.5 MM PER DATASHEET); SHIM THE STANDOFFS TO
SET THE GAP.
3. ALIGN WITH A 6 MM PIN IN THE MAGNET POCKET BEFORE TIGHTENING THE SLOT SCREWS.

NEXT ASSY: WT-6C-200 ROLL SPINDLE ASSY

UNLESS OTHERWISE SPECIFIED:

DIMENSIONS ARE IN INCHES

Wind tunnel - motorized 6-component sting balance

Claude (AI-generated) 2026-10-02

BRACKET, ROLL ENCODER

BREAK SHARP EDGES .005-.015

SURFACE FINISH 63 µin Ra MAX

CLEAR ANODIZE TYPE II

INTERPRET PER ASME Y14.5-2018

UNDIMENSIONED GEOMETRY PER STEP MODEL

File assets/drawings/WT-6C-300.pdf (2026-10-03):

8

7

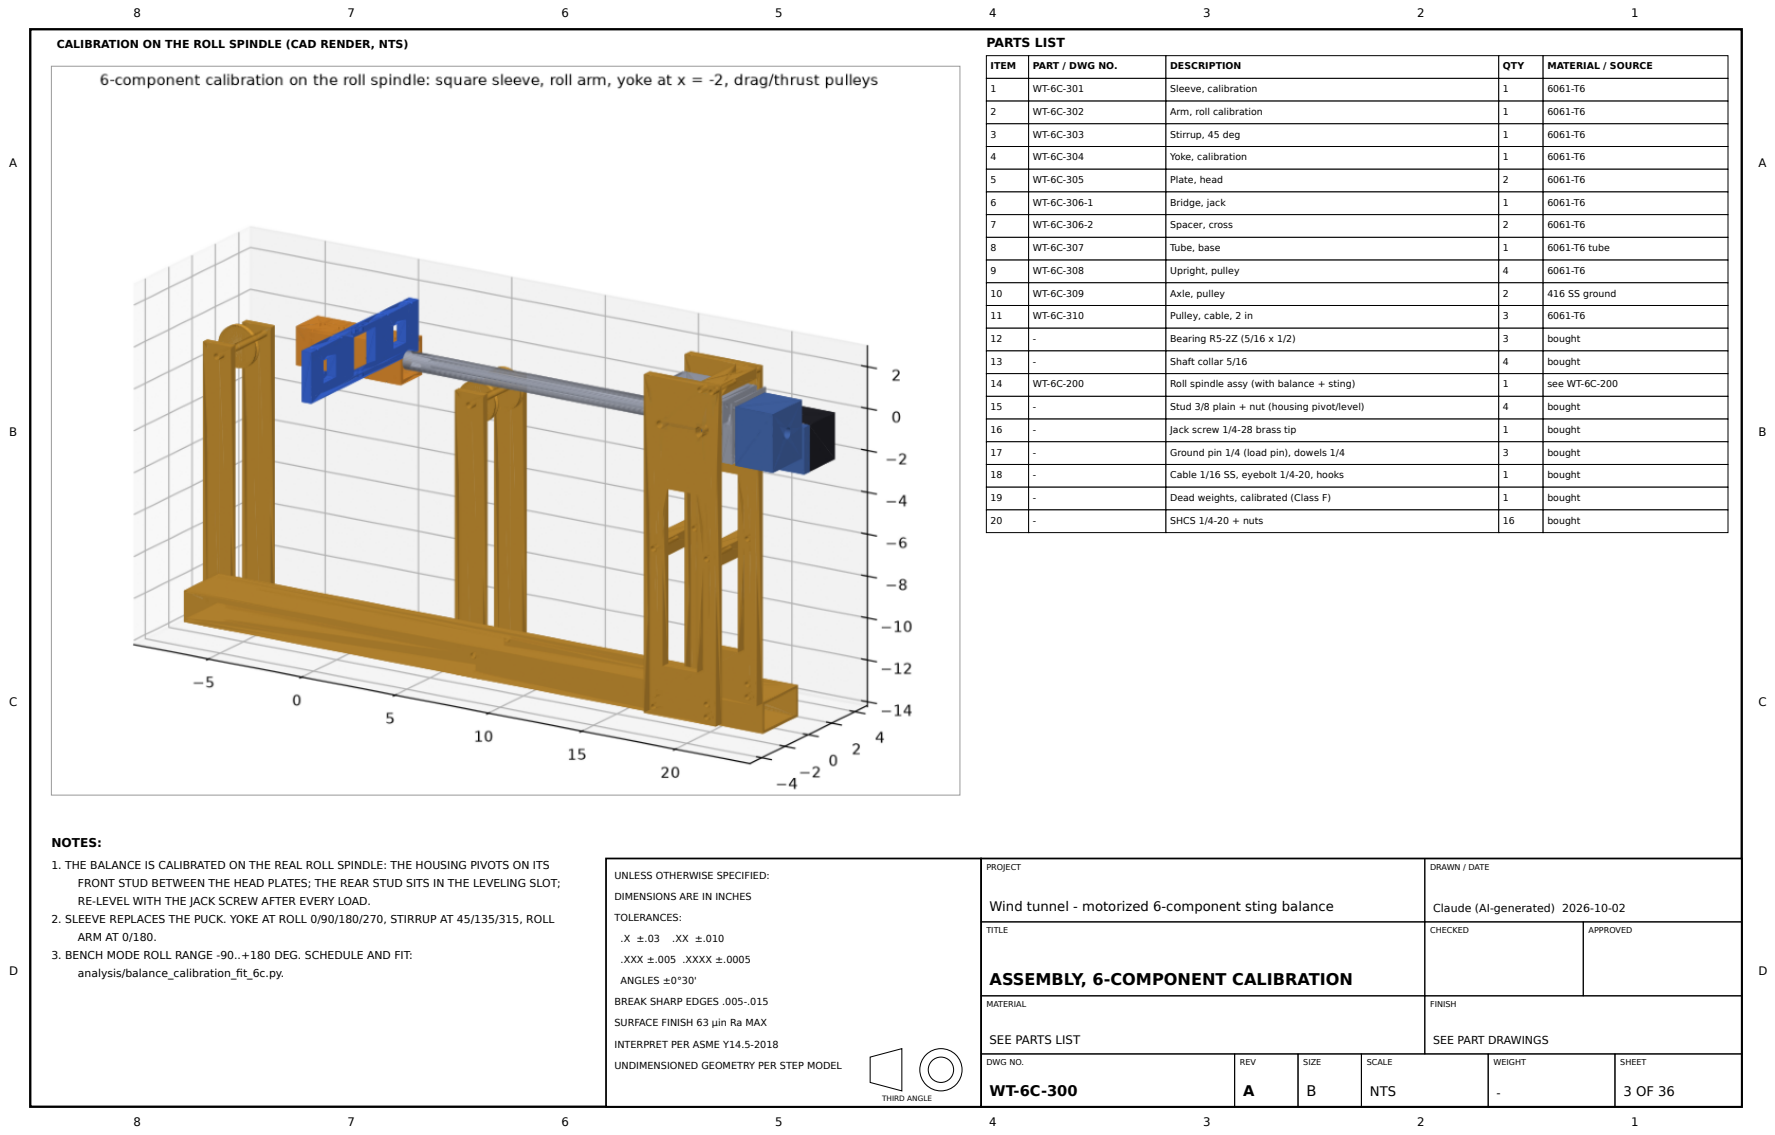
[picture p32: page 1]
CALIBRATION ON THE ROLL SPINDLE (CAD RENDER, NTS); PARTS LIST

ITEM | PART / DWG NO. | DESCRIPTION | QTY | MATERIAL / SOURCE

1 | WT-6C-301 | Sleeve, calibration | 1 | 6061-T6

2 | WT-6C-302 | Arm, roll calibration | 1 | 6061-T6

3 | WT-6C-303 | Stirrup, 45 deg | 1 | 6061-T6

4 | WT-6C-304 | Yoke, calibration | 1 | 6061-T6

5 | WT-6C-305 | Plate, head | 2 | 6061-T6

6 | WT-6C-306-1 | Bridge, jack | 1 | 6061-T6

7 | WT-6C-306-2 | Spacer, cross | 2 | 6061-T6

8 | WT-6C-307 | Tube, base | 1 | 6061-T6 tube

9 | WT-6C-308 | Upright, pulley | 4 | 6061-T6

10 | WT-6C-309 | Axle, pulley | 2 | 416 SS ground

11 | WT-6C-310 | Pulley, cable, 2 in | 3 | 6061-T6

12 | - | Bearing R5-2Z (5/16 x 1/2) | 3 | bought

13 | - | Shaft collar 5/16 | 4 | bought

14 | WT-6C-200 | Roll spindle assy (with balance + sting) | 1 | see WT-6C-200

15 | - | Stud 3/8 plain + nut (housing pivot/level) | 4 | bought

16 | - | Jack screw 1/4-28 brass tip | 1 | bought

17 | - | Ground pin 1/4 (load pin), dowels 1/4 | 3 | bought

18 | - | Cable 1/16 SS, eyebolt 1/4-20, hooks | 1 | bought

19 | - | Dead weights, calibrated (Class F) | 1 | bought

20 | - | SHCS 1/4-20 + nuts | 16 | bought

NOTES:
1. THE BALANCE IS CALIBRATED ON THE REAL ROLL SPINDLE: THE HOUSING PIVOTS ON ITS
FRONT STUD BETWEEN THE HEAD PLATES; THE REAR STUD SITS IN THE LEVELING SLOT;
RE-LEVEL WITH THE JACK SCREW AFTER EVERY LOAD.
2. SLEEVE REPLACES THE PUCK. YOKE AT ROLL 0/90/180/270, STIRRUP AT 45/135/315, ROLL
ARM AT 0/180.
3. BENCH MODE ROLL RANGE -90..+180 DEG. SCHEDULE AND FIT:
analysis/balance_calibration_fit_6c.py.

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

TITLE ASSEMBLY, 6-COMPONENT CALIBRATION | CHECKED | APPROVED

MATERIAL SEE PARTS LIST | FINISH SEE PART DRAWINGS

DWG NO. WT-6C-300 | REV A | SIZE B | SCALE NTS | WEIGHT - | SHEET

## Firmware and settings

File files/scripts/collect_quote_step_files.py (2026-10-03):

r"""
Collect the STEP files of every custom METAL part (no assemblies, no bought-part envelopes, no printed parts, no
superseded designs) into Quote-Part-Step-Files/ for quoting (e.g. JLCCNC), named <drawing no>_<part>.step, plus a
manifest (quantity, material, finish, drawing, notes). Parts that only exist inside a drawing script or as part of a
bought component are exported here (STEP in mm, like all project STEP files).

Run from the project root:  .venv\Scripts\python tools\collect_quote_step_files.py
"""
import csv
import shutil
import sys
from pathlib import Path

ROOT = Path(__file__).resolve().parents[1]
CAD = ROOT / "cad"
OUT = ROOT / "Quote-Part-Step-Files"
DWG = CAD / "drawings"
IN = 25.4

# (drawing, name, source STEP (relative to cad/) or None if exported below, qty, material, finish, notes)
PARTS = [
    ("WT-6C-001", "balance_6c", "six_component_balance/balance_6c_7075.step", 1, "7075-T651", "none (no anodize)",
     "Wire EDM necks/flexures; +-.0005 in sections; CMM report requested. Tighter than JLCCNC standard +-0.05 mm: upload the PDF drawing."),
    ("WT-6C-002", "puck_model_interface", "six_component_balance/model_puck_6061.step", 1, "6061-T6",
     "clear anodize II", "Dowel holes +.0005; face flat .0005 - upload drawing."),
    ("WT-6C-003", "sting", "six_component_balance/sting_4140.step", 1, "4140 pre-hard 28-32 HRC (ask for 42CrMo; 45# steel is the JLCCNC fallback)",
     "black oxide", "0.300 in bore x 17 in (gun drill); OD ground .8740-.8750, straightness .002."),
    ("WT-6C-004", "pod_reference_2.25in_printed", "six_component_balance/pod_reference_2.25in_printed.step", 1,
     "PC-ABS, 3D PRINTED (JLC3DP); NOT CNC", "as printed",
     "3D-PRINTED PART: internal 0.060 in pressure channels and a nose ring cannot be machined. Choose a 3D-printing "
     "process; clear all channels before use. JLC3DP quoted $112.96 in PC-ABS (2026-10-03)."),
    ("WT-6C-201", "spindle_roll", "roll_spindle/spindle_4140.step", 1, "4140 pre-hard (ask for 42CrMo)",
     "black oxide except seats", "35 k5 bearing seats ground; D-D bore by wire EDM; M35x1.5 thread; keyway."),
    ("WT-6C-202", "housing_roll_spindle", "roll_spindle/housing_6061.step", 1, "6061-T6",
     "clear anodize II, mask bores", "2x 55 H7 bores line-bored, runout .0005."),
    ("WT-6C-203-1", "cap_front", "roll_spindle/front_cap_6061.step", 1, "6061-T6", "clear anodize II",
     "Pilot lip 2.1640-2.1645 in."),
    ("WT-6C-203-2", "cap_rear", "roll_spindle/rear_cap_6061.step", 1, "6061-T6", "clear anodize II",
     "Pilot lip 2.1640-2.1645 in."),
    ("WT-6C-204", "adapter_gearbox", "roll_spindle/gearbox_adapter_6061.step", 1, "6061-T6", "clear anodize II",
     "Gearbox hole pattern per NMRV030 vendor drawing (confirm)."),
    ("WT-6C-205", "bracket_roll_encoder", "roll_spindle/encoder_bracket.step", 1, "6061-T6 (.125 plate)",
     "clear anodize II", ""),
    ("WT-6C-301", "sleeve_calibration", "calibration_6c/sleeve_6c_6061.step", 1, "6061-T6",
     "clear anodize II, mask load holes", "20 reamed load holes .2510-.2520, position .001."),
    ("WT-6C-302", "arm_roll_calibration", "calibration_6c/roll_arm_6061.step", 1, "6061-T6 (.500 plate)",
     "clear anodize II", "Knife-edge V-notches, no burrs."),
    ("WT-6C-303", "stirrup_45deg", "calibration_6c/stirrup_45_6061.step", 1, "6061-T6 (.300 plate)",
     "clear anodize II", ""),
    ("WT-6C-304", "yoke_calibration", "calibration_6c/yoke_6c_6061.step", 1, "6061-T6", "clear anodize II", ""),
    ("WT-6C-305", "plate_head_cal_stand", "calibration_6c/head_plate_v2_6061.step", 2, "6061-T6 (.500 plate)",
     "clear anodize II", "Qty 2, identical."),
    ("WT-6C-306-1", "bridge_jack", "calibration_6c/jack_bridge_v2_6061.step", 1, "6061-T6", "clear anodize II", ""),
    ("WT-6C-306-2", "spacer_cross", "calibration_6c/cross_spacer_6061.step", 2, "6061-T6", "clear anodize II",
     "Qty 2."),
    ("WT-6C-307", "tube_base_cal_stand", "calibration_6c/base_tube_v2.step", 1,
     "6061-T6 rect. tube 3 x 1.5 x .125", "none", "Cut to 31 in and drill (hole table on the drawing)."),
    ("WT-6C-308", "upright_pulley", "calibration_stand/drag_upright.step", 4, "6061-T6 (.375 plate)",
     "clear anodize II", "Qty 4, identical (2 drag + 2 thrust; drag_upright.step = thrust_upright.step)."),
    ("WT-6C-309", "axle_pulley", "calibration_stand/thrust_axle.step", 2, "416 stainless or 4140, 5/16 ground rod",
     "none", "Qty 2 (drag + thrust axle)."),
    ("WT-6C-310", "pulley_cable_2in", "calibration_stand/pulley_2in.step", 3, "6061-T6", "clear anodize II, mask bore",
     "Qty 3 (2 drag + 1 thrust); bore for one R5-2Z bearing each."),
    ("WT-6C-401", "cheek_pitch_sector", "pitch_sector_motorized/cheek_plus_y.step", 2, "6061-T6 (.500 plate)",
     "clear anodize II", "Qty 2, identical (+y and -y). Arc slots profile .002 - upload drawing."),
    ("WT-6C-402", "rack_plate_pitch", "pitch_sector_motorized/rack_plate.step", 1, "6061-T6 (.500 plate)",
     "clear anodize II", "Internal arc rack m1.25 by wire EDM; CAD teeth are simplified - use the drawing gear data."),
    ("WT-6C-403", "plate_base_pitch", "pitch_sector_motorized/base_plate.step", 1, "6061-T6 (.750 plate)",
     "clear anodize II", ""),
    ("WT-6C-404-1", "tie_top_pitch", "pitch_sector_motorized/top_tie.step", 1, "6061-T6", "clear anodize II", ""),
    ("WT-6C-404-2", "spacer_pitch_fwd", "pitch_sector_motorized/spacer0.step", 1, "6061-T6", "clear anodize II", ""),
    ("WT-6C-404-3", "spacer_pitch_aft", "pitch_sector_motorized/spacer1.step", 1, "6061-T6", "clear anodize II", ""),
    ("WT-6C-405", "bracket_pitch_drive", "pitch_sector_motorized/drive_bracket_6061.step", 1, "6061-T6",
     "clear anodize II, mask bore", "22 H7 bearing bore; M6 pattern to confirm with the NMRV030 vendor drawing."),
    ("WT-6C-406", "shaft_pitch_pinion", None, 1, "4140 or 416 stainless", "none",
     "Shaft only (8 h6); the m1.25 20T gear is bought and pinned on."),
    ("WT-6C-501", "rail_yaw_inner", "yaw_carriage/rail_inner.step", 1, "6061-T6 (.500 plate)",
     "hard anodize III preferred", "PRELIMINARY - bay dims TO CONFIRM. CAD edges square: 90 deg V-edges per drawing."),
    ("WT-6C-502", "rail_yaw_outer", "yaw_carriage/rail_outer.step", 1, "6061-T6 (.500 plate)",
     "hard anodize III preferred", "PRELIMINARY - TO CONFIRM. V-edges per drawing."),
    ("WT-6C-503", "rack_yaw_floor", "yaw_carriage/floor_rack.step", 1, "6061-T6", "clear anodize II",
     "PRELIMINARY - TO CONFIRM. External arc rack m1.25 by wire EDM; CAD teeth simplified."),
    ("WT-6C-504", "plate_yaw_carriage", "yaw_carriage/carriage_plate_6061.step", 1, "6061-T6 (.500 plate)",
     "clear anodize II", "PRELIMINARY - front edge R12.400 and wheel-stud radii TO CONFIRM."),
    ("WT-6C-506-1", "spacer_wheel_plain", None, 4, "6061-T6 (or 303 stainless)", "clear anodize II",
     "PRELIMINARY."),
    ("WT-6C-506-2", "spacer_wheel_eccentric", None, 4, "6061-T6 (or 303 stainless)", "clear anodize II",
     "PRELIMINARY. Eccentric preload spacer."),
]
GEN_CAD_COPY = {"WT-6C-406": "pitch_sector_motorized/pinion_shaft_8mm.step",
                "WT-6C-506-1": "yaw_carriage/wheel_spacer_plain.step",
                "WT-6C-506-2": "yaw_carriage/wheel_spacer_eccentric.step"}
EXCLUDED = [
    ("WT-6C-505", "yaw pinion: a bought stock m1.25 20T gear, modified (rebore/keyway) - buy the gear with the right bore"),
    ("WT-6C-406 gear", "bought stock m1.25 20T spur gear"),
    ("bought parts", "bearings, KM7 locknut, NMRV030 + gearmotors, NEMA motors, cam followers, V-wheels, encoders, fasteners"),
    ("assemblies", "assembly_*.step files"),
    ("superseded", "aluminum_balance/, printed_pps_balance/, creep_test_coupon/, aoa_mechanism/ and the 3-component stand head/foot/jack bridge/yoke/base tube"),
]


def export_generated():
    """Parts that exist only inside a script or a bought-part model."""
    import cadquery as cq
    sys.path.insert(0, str(DWG))
    sys.path.insert(0, str(CAD / "pitch_sector_motorized"))
    out = {}
    import build_pitch_sector_cad as P
    shaft = (cq.Workplane("XZ").center(P.R_PIN_C, 0).circle(0.157).extrude(1.2)
             .translate((0, -2.55 + 0.6, 0)))
    out["WT-6C-406"] = shaft
    import sheets_yaw as SY
    out["WT-6C-506-1"] = SY.make_spacer(False)
    out["WT-6C-506-2"] = SY.make_spacer(True)
    return out


def main():
    OUT.mkdir(exist_ok=True)
    gen = export_generated()
    import cadquery as cq
    rows = []
    for dwg, name, src, qty, mat, fin, note in PARTS:
        fname = f"{dwg}_{name}.step"
        if src:
            shutil.copy2(CAD / src, OUT / fname)
        else:
            cq.exporters.export(cq.Workplane().add(gen[dwg].val().scale(IN)), str(OUT / fname))
            shutil.copy2(OUT / fname, CAD / GEN_CAD_COPY[dwg])
        pdf = dwg.rsplit("-", 1)[0] if dwg.count("-") == 3 else dwg
        pdf_path = DWG / f"{pdf}.pdf"
        rows.append(dict(file=fname, drawing=dwg, part=name, qty=qty, material=mat, finish=fin,
                         drawing_pdf=f"cad/drawings/{pdf}.pdf" if pdf_path.exists() else "(none yet)", notes=note))
    with open(OUT / "parts_manifest.csv", "w", newline="", encoding="utf-8") as f:
        w = csv.DictWriter(f, fieldnames=list(rows[0].keys()))
        w.writeheader()
        w.writerows(rows)
    n_pcs = sum(r["qty"] for r in rows)
    lines = ["# Quote package - custom metal parts", "",
             f"{len(rows)} STEP files ({n_pcs} pieces for one set). STEP units are **millimetres**. Generated by "
             "`tools/collect_quote_step_files.py`; quantities, materials and finishes are in `parts_manifest.csv`.", "",
             "Quoting notes (JLCCNC):",
             "- JLCCNC's standard tolerance is +-0.05 mm (+-.002 in). For the precision parts (balance, puck, sting, "
             "spindle, housing, caps, sleeve, cheeks, racks, drive bracket) upload the PDF drawing from `cad/drawings/` "
             "with the STEP and ask them to quote to the drawing tolerances.",
             "- JLCCNC's steel options are 45# and SUS304; the sting and spindle are 4140 pre-hard - ask for 42CrMo "
             "(the Chinese equivalent), or quote them elsewhere.",
             "- The 5xx yaw-carriage parts are PRELIMINARY (bay dimensions TO CONFIRM): quote for budget only.",
             "- The racks' CAD teeth are simplified; the drawings give the gear data.",
             "- US duty on Chinese aluminium/steel parts is pre-collected by JLCCNC (about 90 % aluminium, 80 % steel), "
             "shipped DDP.", "", "| File | Qty | Material | Finish | Notes |", "|---|---|---|---|---|"]
    lines += [f"| {r['file']} | {r['qty']} | {r['material']} | {r['finish']} | {r['notes']} |" for r in rows]
    lines += ["", "Not included:"] + [f"- {a}: {b}" for a, b in EXCLUDED]
    (OUT / "README.md").write_text("\n".join(lines) + "\n", encoding="utf-8")
    print(f"{len(rows)} STEP files, {n_pcs} pieces -> {OUT}")


if __name__ == "__main__":
    main()

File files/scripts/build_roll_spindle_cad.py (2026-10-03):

r"""
Roll spindle (+-90 deg) at the sting root, for the six-component balance (cad/six_component_balance).

Layout along the sting axis (x, inches from the BMC; the housing does not roll, everything inside it does):
  16.45  front cap             retains the front bearing outer ring
  16.65  front bearing 6907    35 x 55 x 10 mm deep-groove, sealed
  17.0-20.0  sting flats in the spindle's D-D bore; 2x 1/4-20 bolts at x = 17.75 / 19.25 (top clearance + c'bore,
             bottom tapped) reached through the housing's top windows at roll 0
  19.66  rear bearing 6907     (bearing span 3.0 in), preloaded by a KM7 (M35x1.5) locknut inside the rear cap
  20.50  wire exit             the sting wire bore turns radially out through the spindle, into the adapter window
  20.80-22.80  NMRV030 50:1 worm gearbox (purchased; self-locking), hollow 14 mm output keyed onto the spindle;
               NEMA 23 on its input, pointing +y (sideways)
  23.30  spindle end           6 mm diametric magnet on axis -> AS5048A absolute encoder on a bracket
All drive parts sit more than 21 in from the BMC, outside the pitch-sector cheek band (16.4..20.7 in), so pitch rotation
never sweeps them into the cheeks; the motor points sideways so it stays off the floor at +20 deg pitch.
Purchased parts (gearbox, motor, bearings, locknut) are modelled as envelopes - check the vendor drawings.
Run (from this folder):  ..\..\.venv\Scripts\python build_roll_spindle_cad.py
"""
import math
import sys
from pathlib import Path
import cadquery as cq

HERE = Path(__file__).resolve().parent
sys.path.insert(0, str(HERE.parent / "aluminum_balance"))
sys.path.insert(0, str(HERE.parent / "six_component_balance"))
sys.path.insert(0, str(HERE.parent))
from build_balance_cad import box          # noqa: E402
import build_6c_balance_cad as K           # noqa: E402

IN = 25.4
MM = 1 / 25.4
# bearings 6907: 35 x 55 x 10 mm
B_ID, B_OD, B_W = 35 * MM, 55 * MM, 10 * MM
LIP = 0.04                          # cap pilot lip that clamps each bearing outer ring
X_BF0 = 16.65                       # front bearing front face
X_BR1 = X_BF0 + 3.0 + B_W           # rear bearing rear face (span 3.0 in centre-centre)
X_BR0 = X_BR1 - B_W
HOUS_HALF = 1.45                    # housing 2.90 x 2.90 square
CAP_T = 0.20
REAR_CAP_BORE = 2.10                # clears the KM7 locknut (52 mm = 2.047 in), lip still bears on the outer ring
X_HOUS0, X_HOUS1 = X_BF0 - LIP, X_BR1 + LIP     # housing body
X_CAPF0 = X_HOUS0 - CAP_T
X_CAPR1 = X_HOUS1 + CAP_T
SHOULDER_D = 1.50                   # spindle body between bearings
HOUSING_INNER_D = 1.70
ADAPTER = (X_CAPR1, X_CAPR1 + 0.55)
GBX = (ADAPTER[1] + 0.05, ADAPTER[1] + 2.05)      # NMRV030 envelope along x
GBX_HALF = 1.25
GBX_CD = 30 * MM                    # worm centre distance (input axis below the output)
DRIVE_D = 14 * MM
X_END = GBX[1] + 0.50
X_WIRE = ADAPTER[0] + 0.25
STING_BOLTS = (17.75, 19.25)
FOLLOWERS = (17.3, 19.4)            # cam-follower studs, both side faces: kept over the clearance bore
STUD_DEPTH = 0.45                   # (wall there is 0.60 thick; deeper would break into the bore)


def cyl(d, x0, x1, y=0.0, z=0.0):
    return cq.Workplane("YZ").center(y, z).circle(d / 2).extrude(x1 - x0).translate((x0, 0, 0))


def ring(od, idd, x0, x1):
    return cyl(od, x0, x1).cut(cyl(idd, x0 - 0.01, x1 + 0.01))


# ================================================================== spindle (4140, rotates with the sting)
def make_spindle():
    x_nose = X_CAPF0
    s = cyl(1.30, x_nose, X_BF0)                                   # nose through the front cap
    s = s.union(cyl(B_ID, X_BF0, X_BF0 + B_W))                     # front bearing seat
    s = s.union(cyl(SHOULDER_D, X_BF0 + B_W, X_BR0))               # body / bearing shoulders
    s = s.union(cyl(B_ID, X_BR0, X_BR1))                           # rear bearing seat
    s = s.union(cyl(B_ID - 0.02, X_BR1, X_BR1 + 0.38))             # M35x1.5 thread for the KM7 locknut
    s = s.union(cyl(1.0, X_BR1 + 0.38, ADAPTER[1] + 0.02))         # wire-exit neck
    s = s.union(cyl(DRIVE_D, ADAPTER[1] + 0.02, GBX[1] + 0.05))    # 14 mm keyed drive shaft through the gearbox
    s = s.union(cyl(0.50, GBX[1] + 0.05, X_END))                   # encoder end
    # sting bore: round ahead of the flats, D-D over the flats (x 17..20)
    r_st = K.STING_D / 2 + 0.0025
    x_flat0, x_sting_end = 20.0 - 3.0, 20.0
    s = s.cut(cyl(2 * r_st, x_nose - 0.01, x_flat0))
    dd = cyl(2 * r_st, x_flat0, x_sting_end + 0.01).intersect(box(x_flat0 - 0.1, x_sting_end + 0.1, -1, 1, -0.3525, 0.3525))
    s = s.cut(dd)
    # wire path: axial 0.30 bore from the sting end to the exit neck, radial exits up and down
    s = s.cut(cyl(0.30, x_sting_end - 0.01, X_WIRE + 0.15))
    s = s.cut(cq.Workplane("XY").center(X_WIRE, 0).circle(0.125).extrude(2, both=True))
    # sting bolts: top clearance + c'bore, bottom tapped 1/4-20
    for xb in STING_BOLTS:
        s = s.cut(cq.Workplane("XY").center(xb, 0).circle(0.1405).extrude(1.0))
        s = s.cut(cq.Workplane("XY").center(xb, 0).circle(0.21).extrude(0.3).translate((0, 0, SHOULDER_D / 2 - 0.28)))
        s = s.cut(cq.Workplane("XY").center(xb, 0).circle(0.1005).extrude(-1.0))
    # 5 mm key on the drive shaft, 6 x 2.5 mm magnet pocket on the end
    s = s.cut(box(ADAPTER[1] + 0.15, GBX[1] - 0.10, -2.5 * MM, 2.5 * MM, DRIVE_D / 2 - 3 * MM, 1))
    s = s.cut(cyl(6 * MM, X_END - 2.5 * MM, X_END + 0.01))
    return s
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

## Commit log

2026-10-03 Publish the sting-balance design package (website) for GitHub Pages
    Static site: 12 pages, 35 GD&T drawing sheets, STEP files, scripts and notes.
    [aoa_angle_bracket.step, aoa_base_plate_6061.step, aoa_cheek_minus_y_6061.step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]
2026-10-03 Add drawing WT-6C-004 (3D-printed reference pod) and the pod's JLCCNC quote line
    [calibration_schedule_6c.csv, calibration_schedule_aluminum.csv, machining_cost_estimate.csv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]
2026-10-03 Reference pod: PC-ABS, 3D printed by JLC3DP ($112.96)
    [pinion_shaft_8mm.step, wheel_spacer_eccentric.step, wheel_spacer_plain.step]
